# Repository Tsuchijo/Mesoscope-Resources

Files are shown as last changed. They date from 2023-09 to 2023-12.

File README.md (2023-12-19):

# TM-Lab-Mesoscope-Resources

## Arduino Code
Installing Arduino IDE:

    Download Arduino IDE:
        Visit the official Arduino website: Arduino Software.
        Choose the appropriate version for your operating system (Windows, macOS, Linux), and download the installer.

    Install Arduino IDE:
        Run the downloaded installer and follow the on-screen instructions.
        On Windows, you might need to install drivers for the Arduino board during the installation process.

    Open Arduino IDE:
        Once installed, open the Arduino IDE.

Installing and Running a Supplied Program:

    Connect Arduino Board:
        Connect your Arduino board to your computer using a USB cable.

    Select Board and Port:
        In the Arduino IDE, go to Tools > Board and select the appropriate Arduino board (e.g., Arduino Uno).
        Also, go to Tools > Port and select the port to which your Arduino board is connected.

    Open a Supplied Program (Sketch):
        Download the sketch from TriggeringstrobingArduinoCode/
        In the Arduino IDE, go to File > open and open the downloaded sketch

    Verify the Sketch:
        Click the checkmark icon (Verify) to check for any errors in the code. Fix any errors if they occur.

    Upload the Sketch:
        Click the right arrow icon (Upload) to compile and upload the sketch to the Arduino board.

## Lens Adapters

All the lens adapters are parametrically created using this onshape file:

https://cad.onshape.com/documents/2f0def30531779d17ee9e510/w/bf5702dd5ef345ce03ccb7df/e/dbd37cfbbbade1fbfb717a2f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

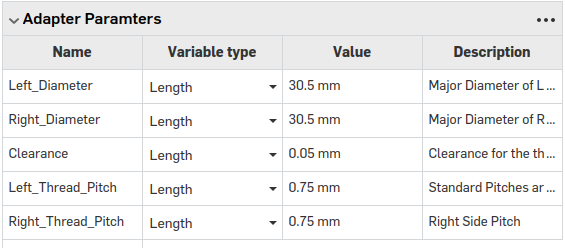
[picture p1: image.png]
Image of the adapter parameters


Adjust these parameters to change the adapters parameters, the diameter is the inner diameter of the lens, pitch is usually 0.5 or 0.75

## Strobing Trigger

### Circuit Diagrams
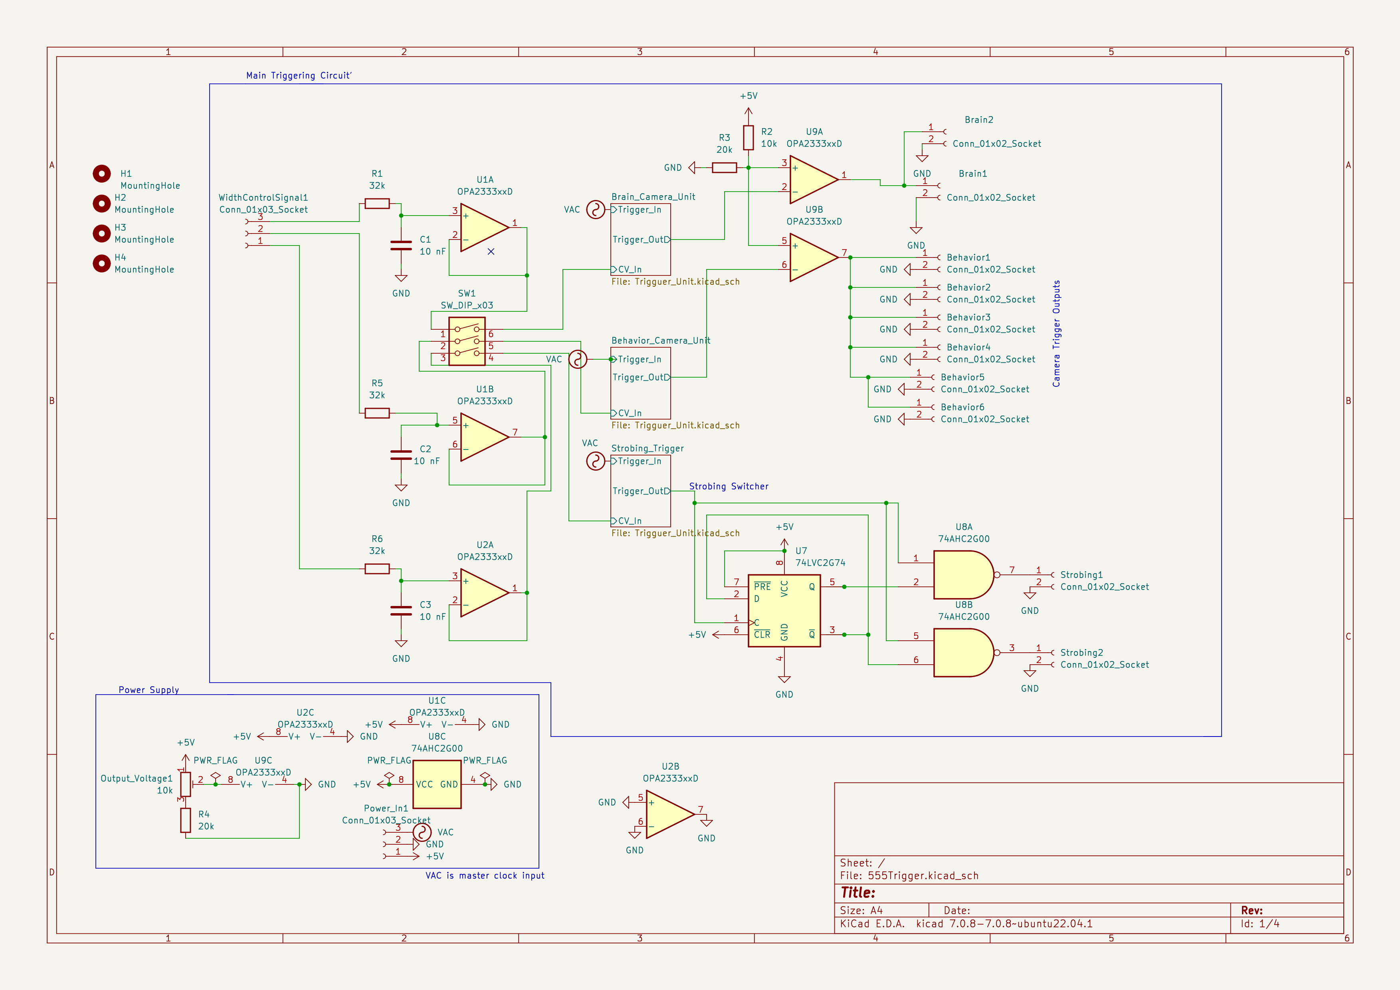
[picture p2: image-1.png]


### Triggering Unit 
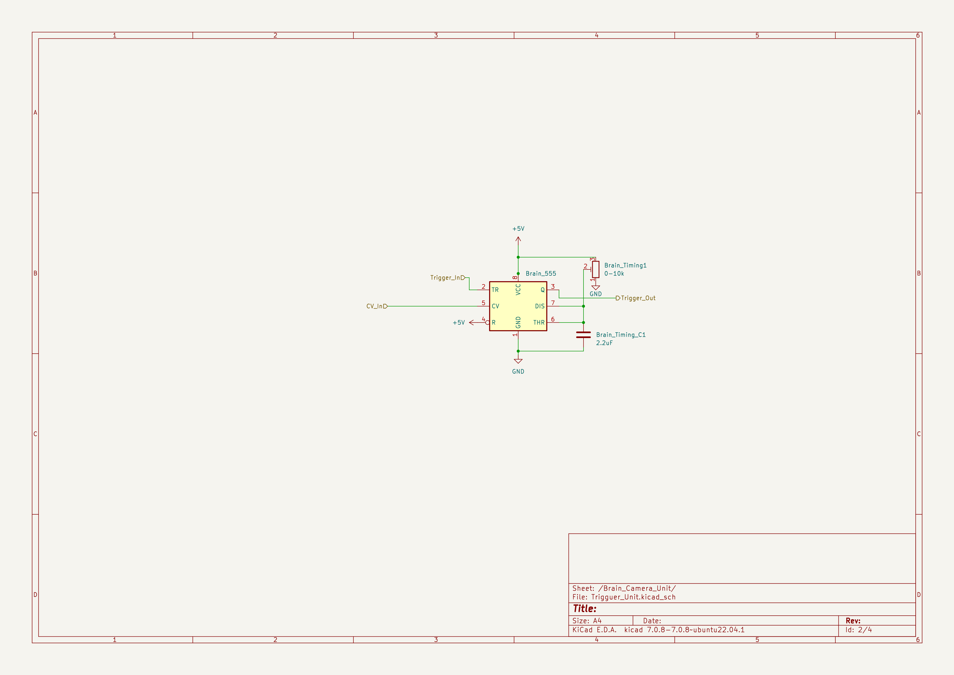
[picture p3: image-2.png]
Sub unit diagram


### Routing 
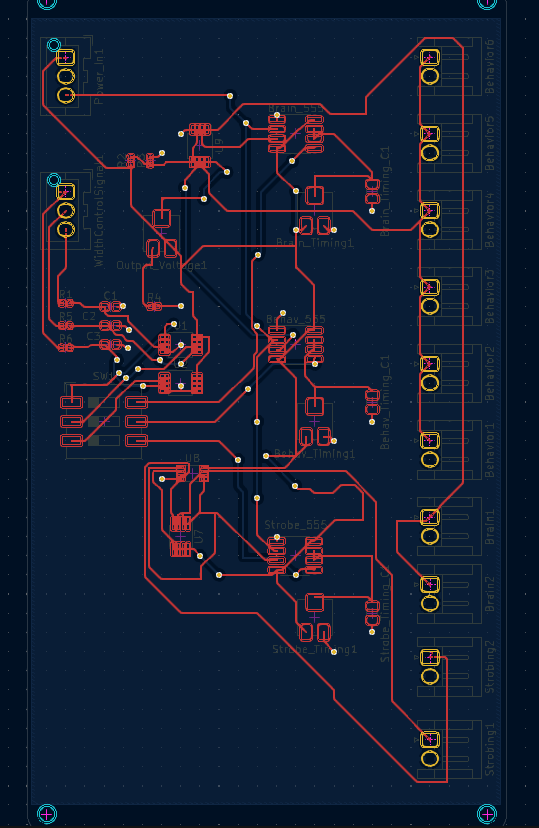
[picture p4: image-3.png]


### I/O
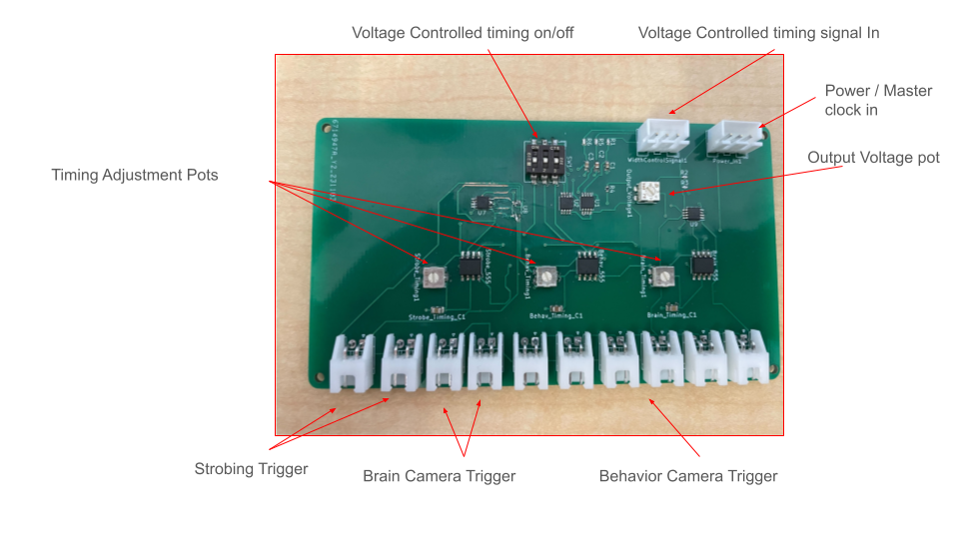
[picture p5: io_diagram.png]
io diagram


For the Master Clock in / power in pin out from left to right is 
- master clock
- ground
- power (5v)

for Timing signal the pinout is
- Brain timing control
- Behavior timing control
- Strobing timing control

with the switches controlling in the same order.

In order to control the width of the timing signal supply a pwm signal to each of the width control signals, with the width corresponding to change in signal. The supplied signal should be greater than 1khz and ideally as high frequency as possible to reduce artifacts

the timing and output pots allow for manual control of timing and output voltage, although each of them can cause errors if pushed to their limits due to variation in their ranges from manufacturing. Never turn the timing pots all the way to the right as that might cause a short

### Using

To use supply a 50hz PWM signal to the master clock with as wide a PWM as possible, the width of the signal corresponding to the maximum possible exposure time.

Supply a 5khz PWM signal for each width control pin in to control the exposure for brain and the behaviour cameras independently. Make sure the switch is switched to ON for the control pin being used. The Width of the PWM signal corresponds with the timing, with the widest signal being the longest exposure time.

Simulation of the circuit can be found at: https://tinyurl.com/ykhpxhtl

### Control Example Code
```import RPi.GPIO as GPIO
import time

# Set GPIO mode and warning
GPIO.setmode(GPIO.BCM)
GPIO.setwarnings(False)

# Define the pin numbers
master_clock_pin = 17
width_control_pin = 18

# Set the frequency for the master clock (50Hz)
master_clock_frequency = 50

# Set the duty cycle for the master clock (99% width)
master_clock_duty_cycle = 99

# Set the frequency for the width control (5kHz)
width_control_frequency = 5000

# Initialize the GPIO pins
GPIO.setup(master_clock_pin, GPIO.OUT)
GPIO.setup(width_control_pin, GPIO.OUT)

# Initialize PWM for master clock
master_clock_pwm = GPIO.PWM(master_clock_pin, master_clock_frequency)
master_clock_pwm.start(master_clock_duty_cycle)

# Function to control the width of the second PWM
def set_width(shutter_speed):
    width_percentage = shutter_speed * 100
    width_control_pwm.ChangeDutyCycle(width_percentage)

# Initialize PWM for width control
width_control_pwm = GPIO.PWM(width_control_pin, width_control_frequency)
width_control_pwm.start(0)  # Start with 0% duty cycle

try:
    # Example: Set shutter speed to 0.5 (50% duty cycle)
    shutter_speed = 0.5
    set_width(shutter_speed)

    # Keep the program running
    while True:
        time.sleep(1)

except KeyboardInterrupt:
    # Clean up on program exit
    master_clock_pwm.stop()
    width_control_pwm.stop()
    GPIO.cleanup()
```

# Throughole Based Triggering System
For making the throughhole 555 trigger there is a .xlsx file with the digikey order needed to create one system. The list can also be found at this link: https://www.digikey.ca/en/mylists/list/3F61W3LRA3. Then the components can be placed on the board based on the silkscreen.

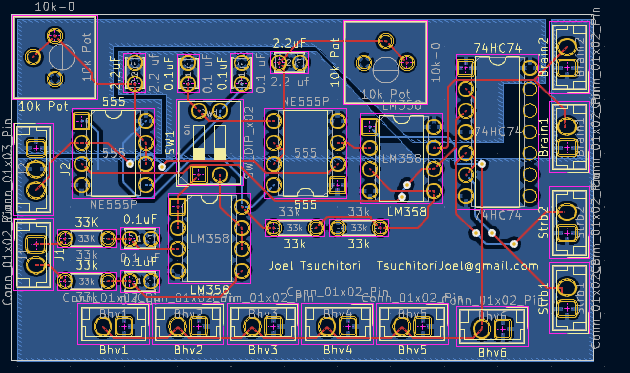
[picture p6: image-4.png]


## Circuit Drawing

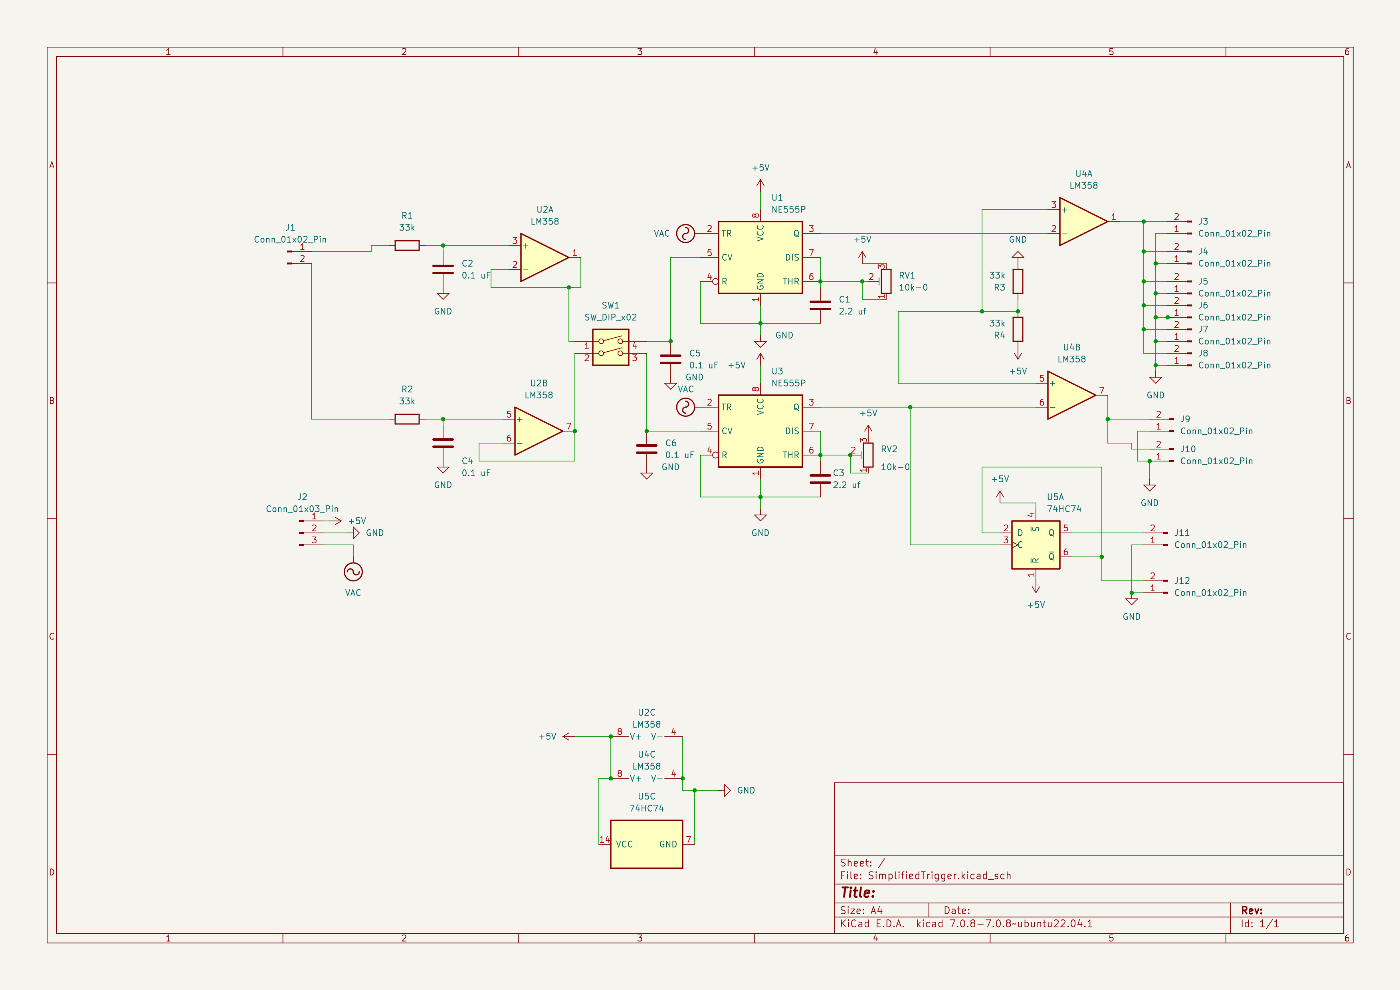
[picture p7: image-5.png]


# Solenoid Driver

The Driver is based on using M7 Mosfet drivers, which max out at ~300 mA of current draw at 12V, anything higher will damage and burn out the driver over time. Not suitable for high power solenoids.

## Circuit Drawing
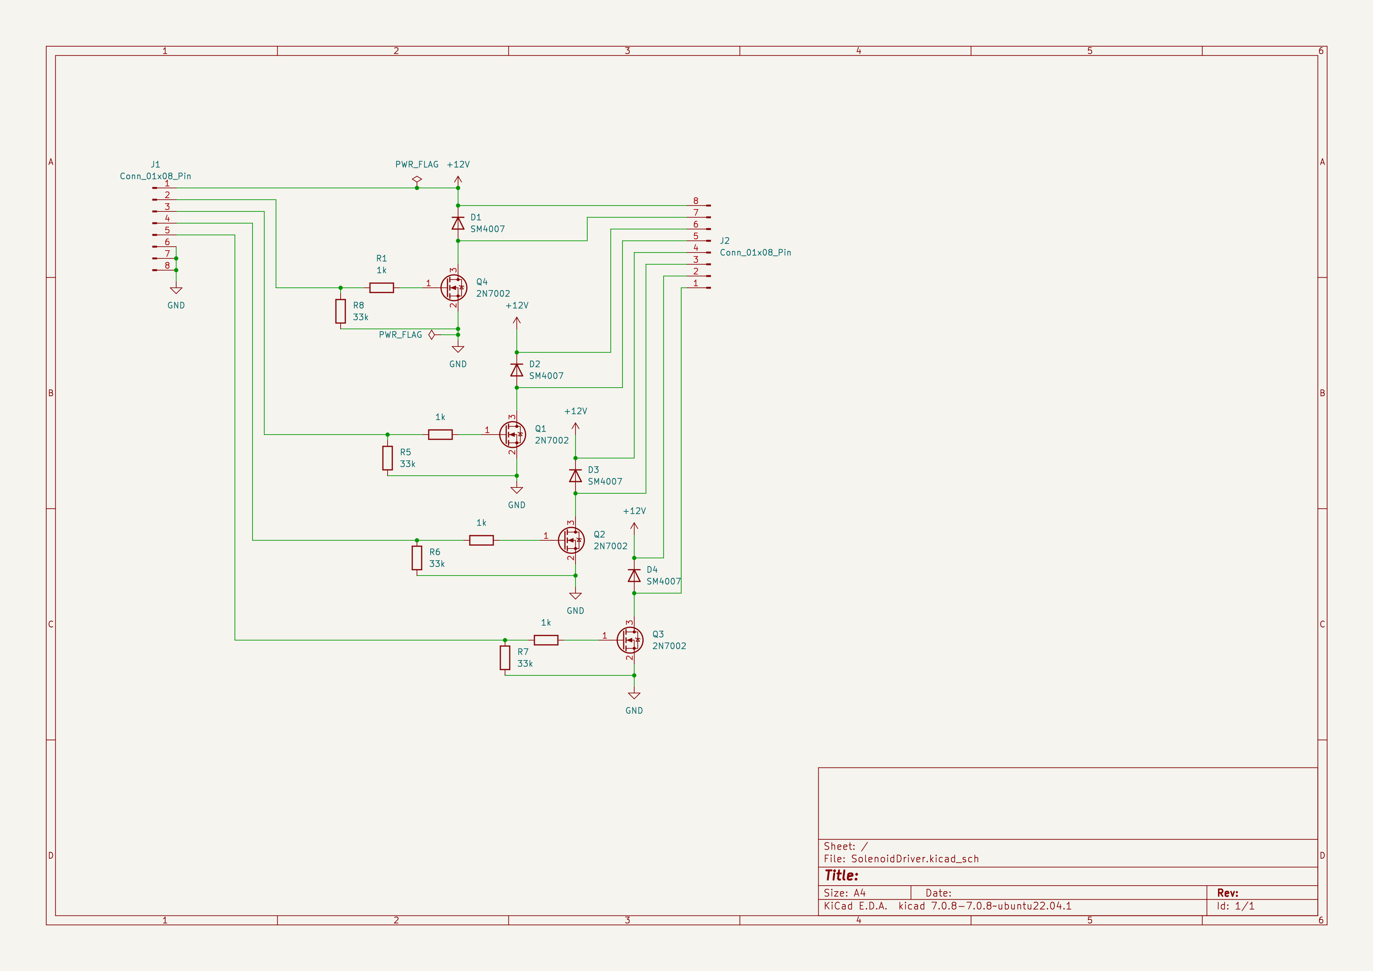
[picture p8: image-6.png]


# Glass Slide Cutting Jigs
https://cad.onshape.com/documents/586ecae177d828403c2f23cb/w/295fcf84d2d2bd0672364755/e/c55ac1745cc839e1a44f1998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

the Glass Slide Cutting Jig is parameterized by a variable table which determines the depth of the first and second cuts, made to cut 8mm diameter glass slides, should be 3d printed on fine print settings.

# Columbia Mouse Cup Clear Sides Model
https://cad.onshape.com/documents/b81ce74945475cb4a4585191/w/58aa1f17095117351b4c242d/e/5ae7ff2c3d7fb6816ba1f3a7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

Clear Sided mouse cup for water reaching task. The sides should be laser cut out of 3mm acrylic, the main cup 3d printed.

# Headfix Mount
https://cad.onshape.com/documents/1d2096fc56ebea0ce0825b22/w/af5d367c825ef3549394acac/e/f6e60455f61b46eaad854045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

Model and Drawing for headfix mount, should be tapped and machined. Used JLCPCB to order the Machined versions.

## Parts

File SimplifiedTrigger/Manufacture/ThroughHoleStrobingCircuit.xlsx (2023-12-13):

Country of Origin may be different at time of shipment.
The HTSUS and ECCN information shown is for informational purposes only and is not a representation or warranty as to the accuracy or reliability of these classifications. All information is provided "as is" and is subject to change without notice. Any use made of the information provided is without recourse to Digi-Key and at the user's risk.
Index | Manufacturer Part Number | Manufacturer Name | Description | Availability | Stock Status | Attrition % | Requested Quantity 1 | Pack Quantity 1 | Pack Type 1 | Digi-Key Part Number 1 | Unit Price 1 | Extended Price 1 | Minimum Order Quantity 1 | Customer Reference | Requested Part Number | Lead Weeks | Datasheet | Reference Designator | US Import Tariff | Note | Part Status | RoHS Status | Moisture Sensitivity Level (MSL) | ECCN | HTSUS | Country of Origin | Environmental Information | Original Part numbers | Image
1 | 3386P-1-103LF | Bourns Inc. | TRIMMER 10K OHM 0.5W PC PIN TOP | 8,644 | In Stock |  | 2 | 2 | Tube | 3386P-103LF-ND | 1.61000 | $3.22 | 1 |  | 3386P-103LF-ND | 11 | https://www.bourns.com/docs/Product-Datasheets/3386.pdf |  | N/A |  | Active | ROHS3 Compliant | Not Applicable | EAR99 | 8533.40.8050 | Costa Rica | https://www.bourns.com/docs/rohs-content/bourns-reach-letter.pdf|https://www.bourns.com/docs/rohs-cofc/cofc_trim3.pdf?sfvrsn=c321a2cb_6 | 3386P-103LF-ND | https://mm.digikey.com/Volume0/opasdata/d220001/medias/images/2383/3386P SERIES.jpg
2 | LM358P | Texas Instruments | IC OPAMP GP 2 CIRCUIT 8DIP | 48,612 | In Stock |  | 2 | 2 | Tube | 296-1395-5-ND | 0.41000 | $0.82 | 1 |  | 296-1395-5-ND | 6 | https://www.ti.com/general/docs/suppproductinfo.tsp?distId=10 |  | May apply on shipments to the U.S. |  | Active | ROHS3 Compliant | Not Applicable | EAR99 | 8542.33.0001 | China |  | 296-1395-5-ND | https://mm.digikey.com/Volume0/opasdata/d220001/medias/images/376/8-DIP.jpg
3 | NE555P | Texas Instruments | IC OSC SINGLE TIMER 100KHZ 8-DIP | 46,237 | In Stock |  | 2 | 2 | Tube | 296-NE555P-ND | 0.46000 | $0.92 | 1 |  | 296-NE555P-ND | 6 | https://www.ti.com/general/docs/suppproductinfo.tsp?distId=10 |  | N/A |  | Active | ROHS3 Compliant | Not Applicable | EAR99 | 8542.39.0001 | Mexico |  | 296-NE555P-ND | https://mm.digikey.com/Volume0/opasdata/d220001/medias/images/376/8-DIP.jpg
4 | CD74HC74E | Texas Instruments | IC FF D-TYPE DUAL 1BIT 14DIP | 2,926 | In Stock |  | 1 | 1 | Tube | 296-12819-5-ND | 0.87000 | $0.87 | 1 |  | 296-12819-5-ND | 6 | https://www.ti.com/general/docs/suppproductinfo.tsp?distId=10 |  | N/A |  | Active | ROHS3 Compliant | Not Applicable | EAR99 | 8542.39.0001 | Malaysia |  | 296-12819-5-ND | https://mm.digikey.com/Volume0/opasdata/d220001/medias/images/4846/296_14-DIP.jpg
5 | B2B-XH-A | JST Sales America Inc. | CONN HEADER VERT 2POS 2.5MM | 1,099,826 | In Stock |  | 11 | 11 | Bulk | 455-B2B-XH-A-ND | 0.12200 | $1.34 | 1 |  | 455-B2B-XH-A-ND | 16 | https://www.jst-mfg.com/product/pdf/eng/eXH.pdf |  | N/A |  | Active | ROHS3 Compliant | 1 (Unlimited) | EAR99 | 8536.69.4040 | China |  | 455-B2B-XH-A-ND | https://mm.digikey.com/Volume0/opasdata/d220001/medias/images/867/B2B-XH-A(LF)(SN).jpg
6 | B3B-XH-A | JST Sales America Inc. | CONN HEADER VERT 3POS 2.5MM | 71,311 | In Stock |  | 1 | 1 | Bulk | 455-2248-ND | 0.21000 | $0.21 | 1 |  | 455-2248-ND | 16 | https://www.jst-mfg.com/product/pdf/eng/eXH.pdf |  | N/A |  | Active | RoHS non-compliant | 1 (Unlimited) | EAR99 | 8536.69.4040 | China |  | 455-2248-ND | https://mm.digikey.com/Volume0/opasdata/d220001/medias/images/889/B3B-XH-A(LF)(SN).jpg
7 | CF18JT33K0 | Stackpole Electronics Inc | RES 33K OHM 5% 1/8W AXIAL | 19,634 | In Stock |  | 4 | 4 | Cut Tape (CT) | CF18JT33K0CT-ND | 0.10000 | $0.40 | 1 |  | CF18JT33K0CT-ND | 17 | https://www.seielect.com/catalog/sei-cf_cfm.pdf |  | May apply on shipments to the U.S. |  | Active | ROHS3 Compliant | Not Applicable | EAR99 | 8533.10.0065 | China | https://www.seielect.com/catalog/cert-of-compliance.pdf|https://www.seielect.com/catalog/reach.pdf|https://www.seielect.com/catalog/SEI-RoHS_Compliance_Status.pdf | CF18JT33K0CT-ND | https://mm.digikey.com/Volume0/opasdata/d220001/medias/images/2453/CF Series 33k.jpg
8 | K104K15X7RF5TL2 | Vishay Beyschlag/Draloric/BC Components | CAP CER 0.1UF 50V X7R RADIAL | 288,776 | In Stock |  | 4 | 4 | Cut Tape (CT) | BC1084CT-ND | 0.23000 | $0.92 | 1 |  | BC1084CT-ND | 17 | https://www.vishay.com/docs/45171/kseries.pdf |  | May apply on shipments to the U.S. |  | Active | ROHS3 Compliant | Not Applicable | EAR99 | 8532.24.0060 | China | https://www.vishay.com/docs/99912/mat_cat_policy.pdf | BC1084CT-ND | https://mm.digikey.com/Volume0/opasdata/d220001/medias/images/4847/56_K102K15X7RF5TL2.jpg
9 | FG14X7R1H225KRT06 | TDK Corporation | CAP CER 2.2UF 50V X7R RADIAL | 9,537 | In Stock |  | 2 | 2 | Cut Tape (CT) | 445-173138-1-ND | 0.52000 | $1.04 | 1 |  | 445-173138-1-ND | 24 | https://product.tdk.com/en/system/files |  | May apply on shipments to the U.S. |  | Active | ROHS3 Compliant | Not Applicable | EAR99 | 8532.24.0060 | China | https://product.tdk.com/en/environment/index.html | 445-173138-1-ND | https://mm.digikey.com/Volume0/opasdata/d220001/medias/images/21/MFG_FG14.JPG
10 | 206-2ST | CTS Electrocomponents | SWITCH SLIDE DIP SPST 50MA 24V | 10,540 | In Stock |  | 1 | 1 | Tube | CT2062ST-ND | 0.83000 | $0.83 | 1 |  | CT2062ST-ND | 12 | https://www.ctscorp.com/wp-content/uploads/206.pdf |  | N/A |  | Active | ROHS3 Compliant | Not Applicable | EAR99 | 8536.50.9065 | Taiwan | https://www.ctscorp.com/wp-content/uploads/ROHS3_DIPTactSwitch.pdf | CT2062ST-ND | https://mm.digikey.com/Volume0/opasdata/d220001/medias/images/4113/MFG_206-2ST.jpg

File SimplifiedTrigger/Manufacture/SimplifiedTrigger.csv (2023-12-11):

Id | Designator | Footprint | Quantity | Designation | Supplier and ref
1 | J1,Brain1,Bhv5,Bhv3,Strb2,Bhv6,Bhv4,Strb1,Bhv2,Brain2,Bhv1 | JST_EH_B2B-EH-A_1x02_P2.50mm_Vertical | 11 | Conn_01x02_Pin
2 | 0.1uF,0.1uF,0.1uF,0.1uF | C_Disc_D3.4mm_W2.1mm_P2.50mm | 4 | 0.1 uF
3 | SW1 | SW_DIP_SPSTx02_Slide_9.78x7.26mm_W7.62mm_P2.54mm | 1 | SW_DIP_x02
4 | 33k,33k,33K,33k | R_Axial_DIN0204_L3.6mm_D1.6mm_P5.08mm_Horizontal | 4 | 33k
5 | 555,555 | DIP-8_W7.62mm | 2 | NE555P
6 | LM358,LM358 | DIP-8_W7.62mm | 2 | LM358
7 | 10k Pot,10k Pot | Potentiometer_Bourns_3386P_Vertical | 2 | 10k-0
8 | 2.2uF,2.2uF | C_Disc_D3.4mm_W2.1mm_P2.50mm | 2 | 2.2 uf
9 | J2 | JST_EH_B3B-EH-A_1x03_P2.50mm_Vertical | 1 | Conn_01x03_Pin
10 | 74HC74 | DIP-14_W7.62mm | 1 | 74HC74

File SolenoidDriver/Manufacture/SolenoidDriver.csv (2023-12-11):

Id | Designator | Footprint | Quantity | Designation | Supplier and ref
1 | R8,R7,R6,R5 | R_0603_1608Metric | 4 | 33k
2 | R4,R3,R2,R1 | R_0603_1608Metric | 4 | 1k
3 | Q4,Q3,Q2,Q1 | SOT-23 | 4 | 2N7002
4 | J2,J1 | PinHeader_1x08_P2.54mm_Vertical | 2 | Conn_01x08_Pin
5 | D4,D3,D2,D1 | D_MELF | 4 | SM4007

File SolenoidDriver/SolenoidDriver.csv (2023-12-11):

# | Reference | Qty | Value | Footprint | DNP
1 | D1, D2, D3, D4 | 4 | SM4007 | Diode_SMD:D_MELF
2 | J1, J2 | 2 | Conn_01x08_Pin | Connector_PinHeader_2.54mm:PinHeader_1x08_P2.54mm_Vertical
3 | Q1, Q2, Q3, Q4 | 4 | 2N7002 | Package_TO_SOT_SMD:SOT-23
4 | R1, R2, R3, R4 | 4 | 1k | Resistor_SMD:R_0603_1608Metric
5 | R5, R6, R7, R8 | 4 | 33k | Resistor_SMD:R_0603_1608Metric

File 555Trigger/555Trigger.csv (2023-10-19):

# | Reference | Qty | Value | Footprint | DNP
1 | Behav_555, Brain_555, Strobe_555 | 3 | TLC555xD | Package_SO:SOIC-8_3.9x4.9mm_P1.27mm
2 | Behav_Timing1, Brain_Timing1, Strobe_Timing1 | 3 | 0-10k | Potentiometer_SMD:Potentiometer_Bourns_3314J_Vertical
3 | Behav_Timing_C1, Brain_Timing_C1, Strobe_Timing_C1 | 3 | 2.2uF | Capacitor_SMD:C_0805_2012Metric
4 | Behavior1, Behavior2, Behavior3, Behavior4, Behavior5, Behavior6, Brain1, Brain2, Strobing1, Strobing2 | 10 | Conn_01x02_Socket | Connector_JST:JST_EH_S2B-EH_1x02_P2.50mm_Horizontal
5 | C1, C2, C3 | 3 | 10 nF | Capacitor_SMD:C_0603_1608Metric
6 | H1, H2, H3, H4 | 4 | MountingHole | MountingHole:MountingHole_2.2mm_M2
7 | Output_Voltage1 | 1 | 10k | Potentiometer_SMD:Potentiometer_Bourns_3314J_Vertical
8 | Power_In1, WidthControlSignal1 | 2 | Conn_01x03_Socket | Connector_JST:JST_XA_B03B-XASK-1-A_1x03_P2.50mm_Vertical
9 | R1, R5, R6 | 3 | 32k | Resistor_SMD:R_0402_1005Metric
10 | R2 | 1 | 10k | Resistor_SMD:R_0402_1005Metric
11 | R3, R4 | 2 | 20k | Resistor_SMD:R_0402_1005Metric
12 | SW1 | 1 | SW_DIP_x03 | Button_Switch_SMD:SW_DIP_SPSTx03_Slide_9.78x9.8mm_W8.61mm_P2.54mm
13 | U1, U2, U9 | 3 | OPA2333xxD | Package_SO:TSSOP-8_3x3mm_P0.65mm
14 | U7 | 1 | 74LVC2G74 | Package_SO:SSOP-8_2.95x2.8mm_P0.65mm
15 | U8 | 1 | 74AHC2G00 | Package_SO:VSSOP-8_2.3x2mm_P0.5mm

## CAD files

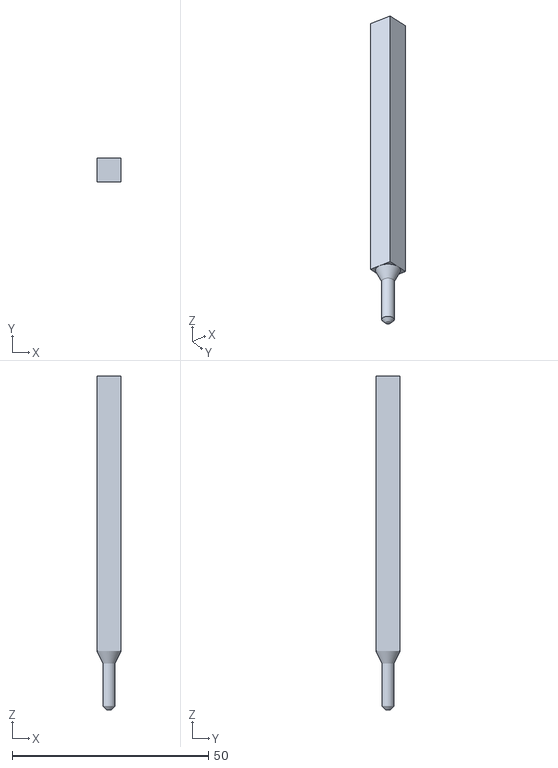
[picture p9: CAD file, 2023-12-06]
Models/EarfixMount.stl
6.21 x 6.21 x 85.0

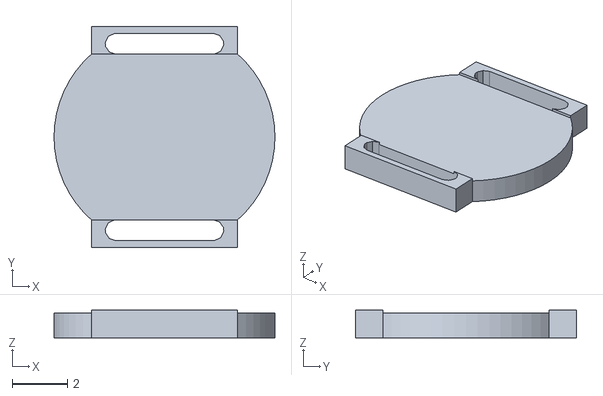
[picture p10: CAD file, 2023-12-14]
Models/GlassCutterJig/Jig2Bottom.stl
8.00 x 8.00 x 1.00

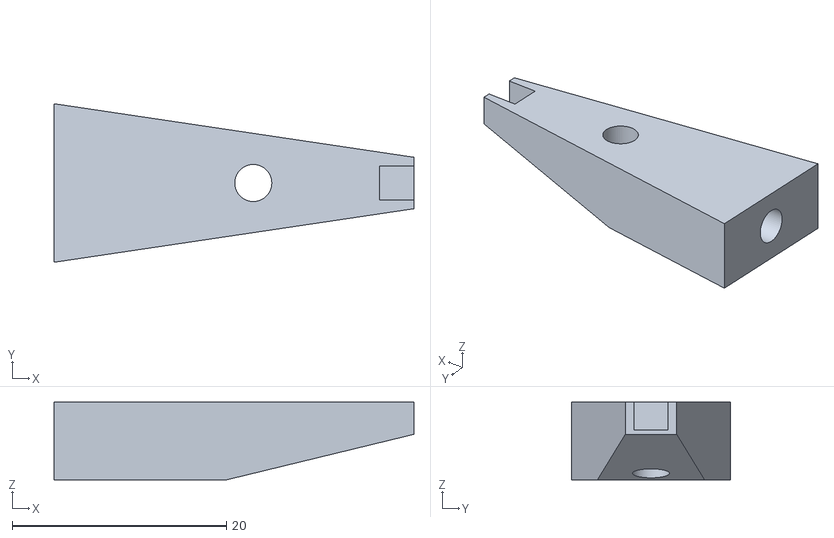
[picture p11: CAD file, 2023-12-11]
Models/Headfix Clamp/HeadClampBottom(1).stl
33.6 x 14.8 x 7.25

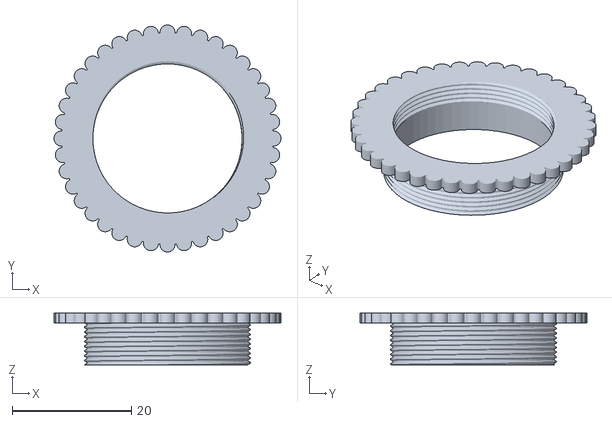
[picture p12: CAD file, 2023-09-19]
Models/LensAdapters/PiCam-Cmount adapter .stl
38.1 x 38.1 x 8.68

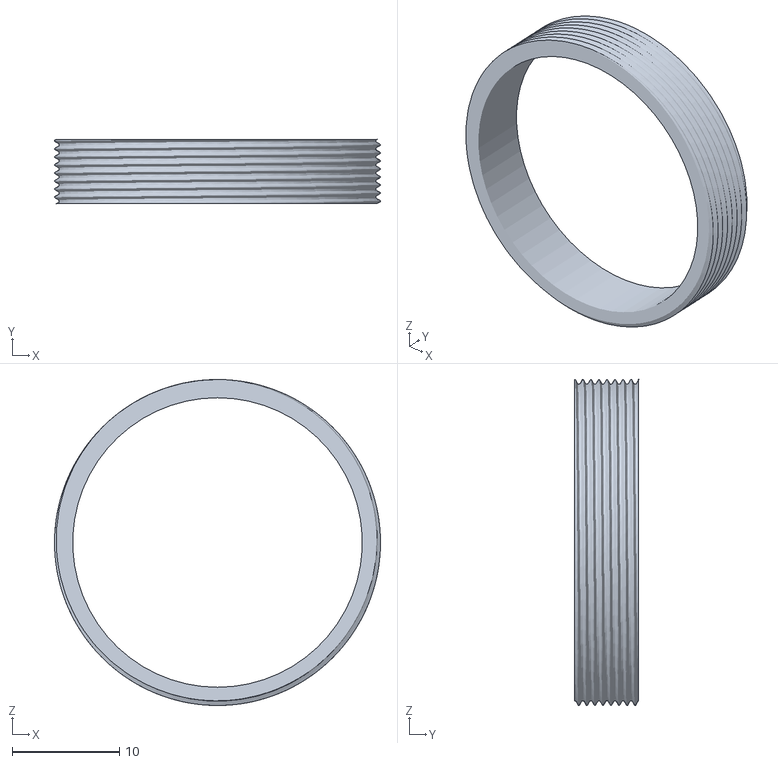
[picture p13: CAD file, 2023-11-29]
Models/LensAdapters/TandemLens/25mm-25mmTandemLensAdapter.stl
30.4 x 6.00 x 30.4

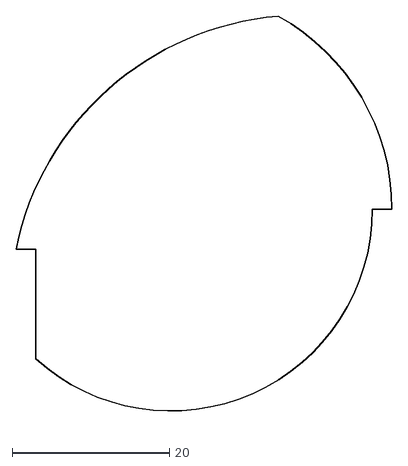
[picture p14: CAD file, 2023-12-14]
Models/MouseCupClear/LaserCutSide.dxf
47.9 x 52.2

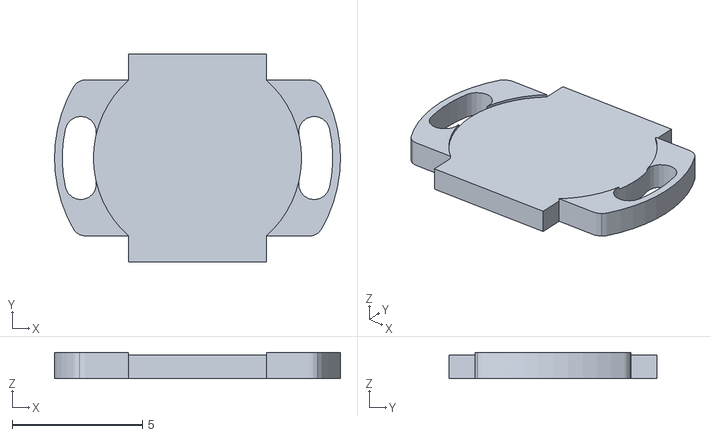
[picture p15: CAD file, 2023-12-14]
Models/GlassCutterJig/Jig1Bottom.stl
11.0 x 8.00 x 1.00

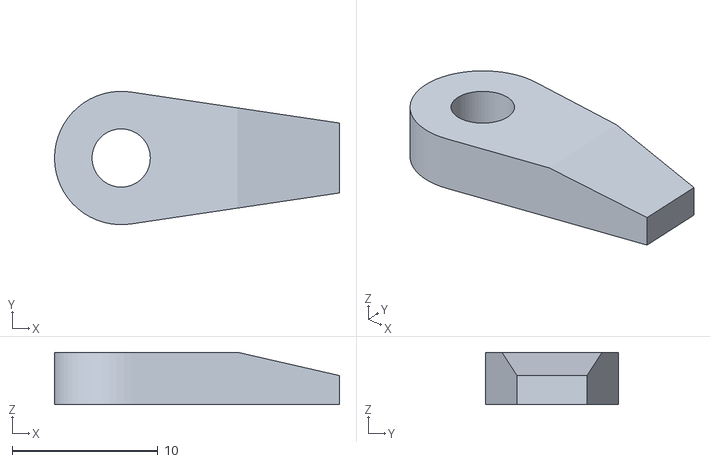
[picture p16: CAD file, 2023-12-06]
Models/Headfix Clamp/HeadClampTop.stl
19.6 x 9.16 x 3.60

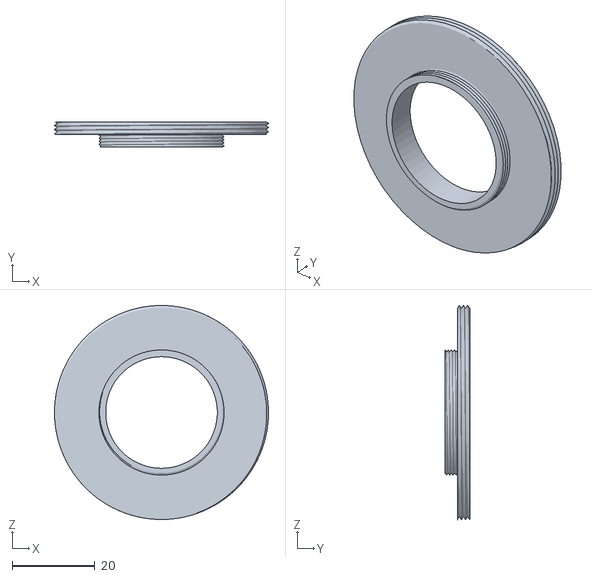
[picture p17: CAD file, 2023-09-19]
Models/LensAdapters/TandemLens/TandemAdapter 30.5-52mm.stl
51.7 x 6.00 x 51.8

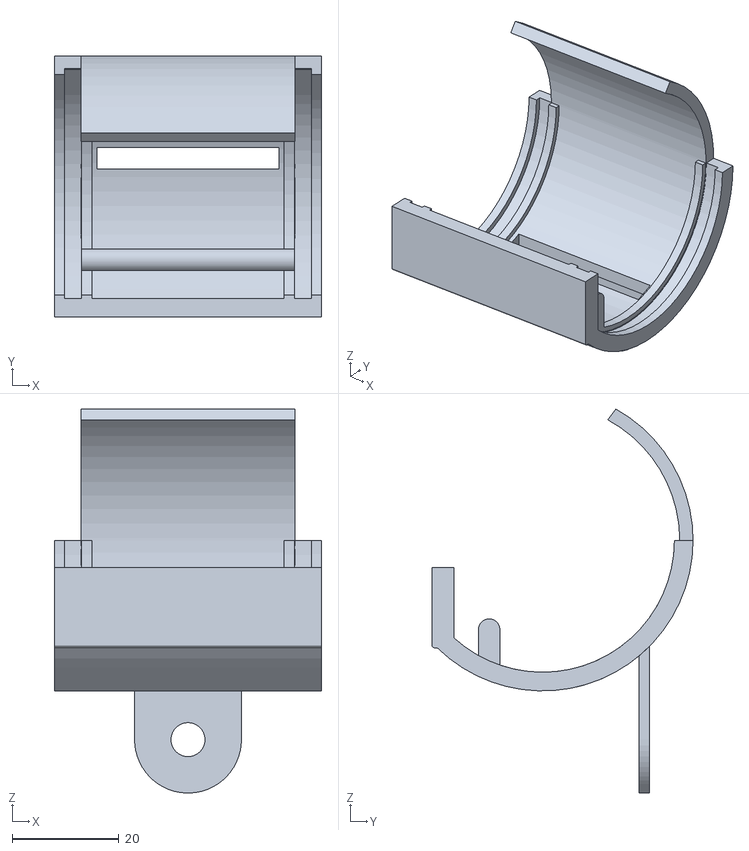
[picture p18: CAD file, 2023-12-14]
Models/MouseCupClear/MouseCupclear.stl
50.0 x 48.9 x 71.8

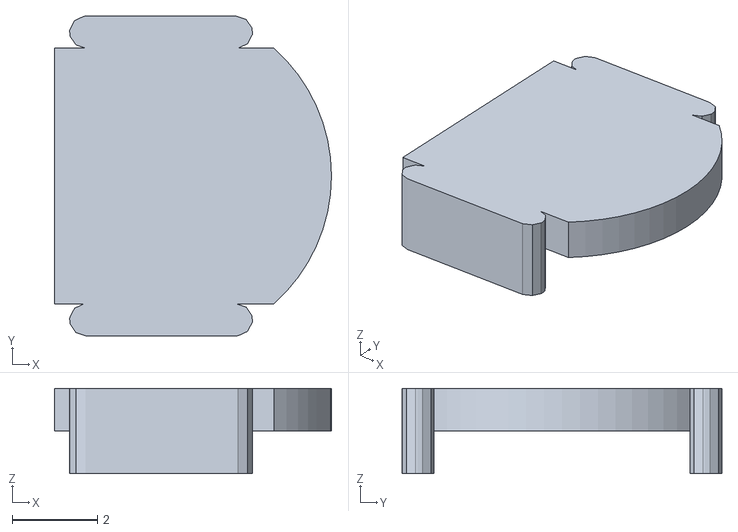
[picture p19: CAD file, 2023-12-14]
Models/GlassCutterJig/Jig2Top.stl
6.50 x 7.50 x 2.00

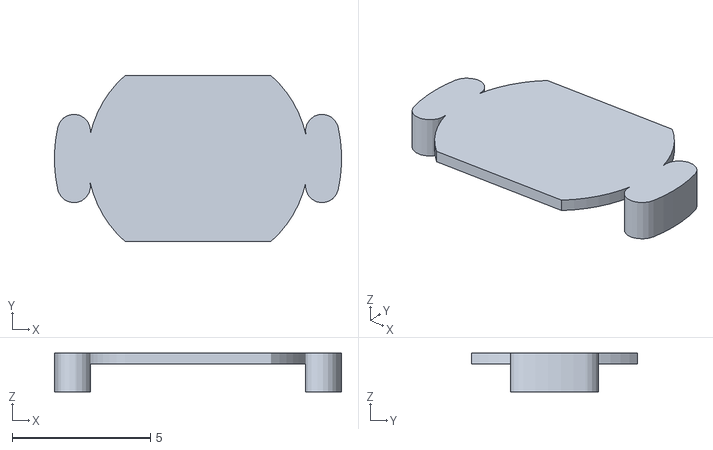
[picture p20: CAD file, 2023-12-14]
Models/GlassCutterJig/Jig1Top.stl
10.4 x 6.00 x 1.40

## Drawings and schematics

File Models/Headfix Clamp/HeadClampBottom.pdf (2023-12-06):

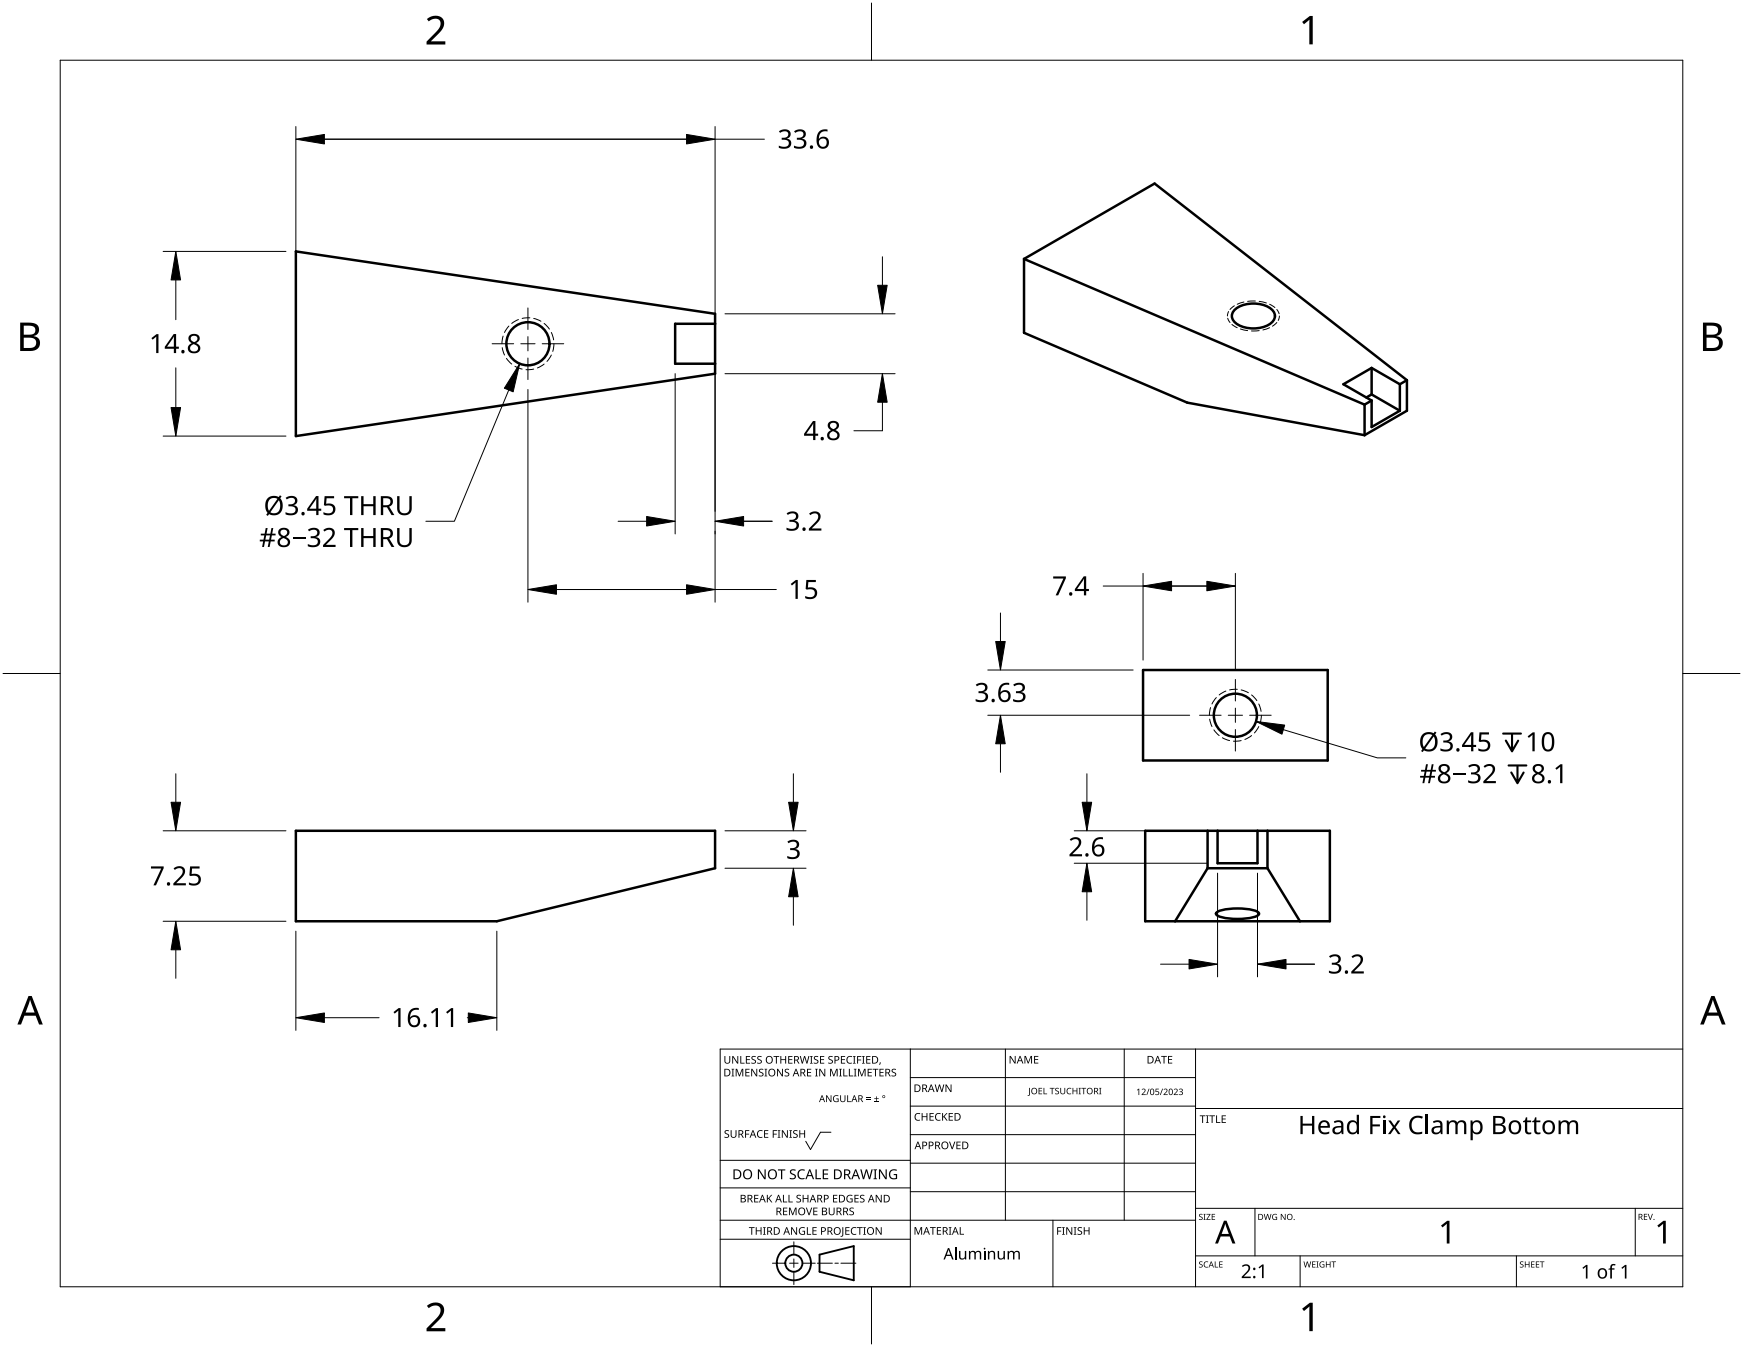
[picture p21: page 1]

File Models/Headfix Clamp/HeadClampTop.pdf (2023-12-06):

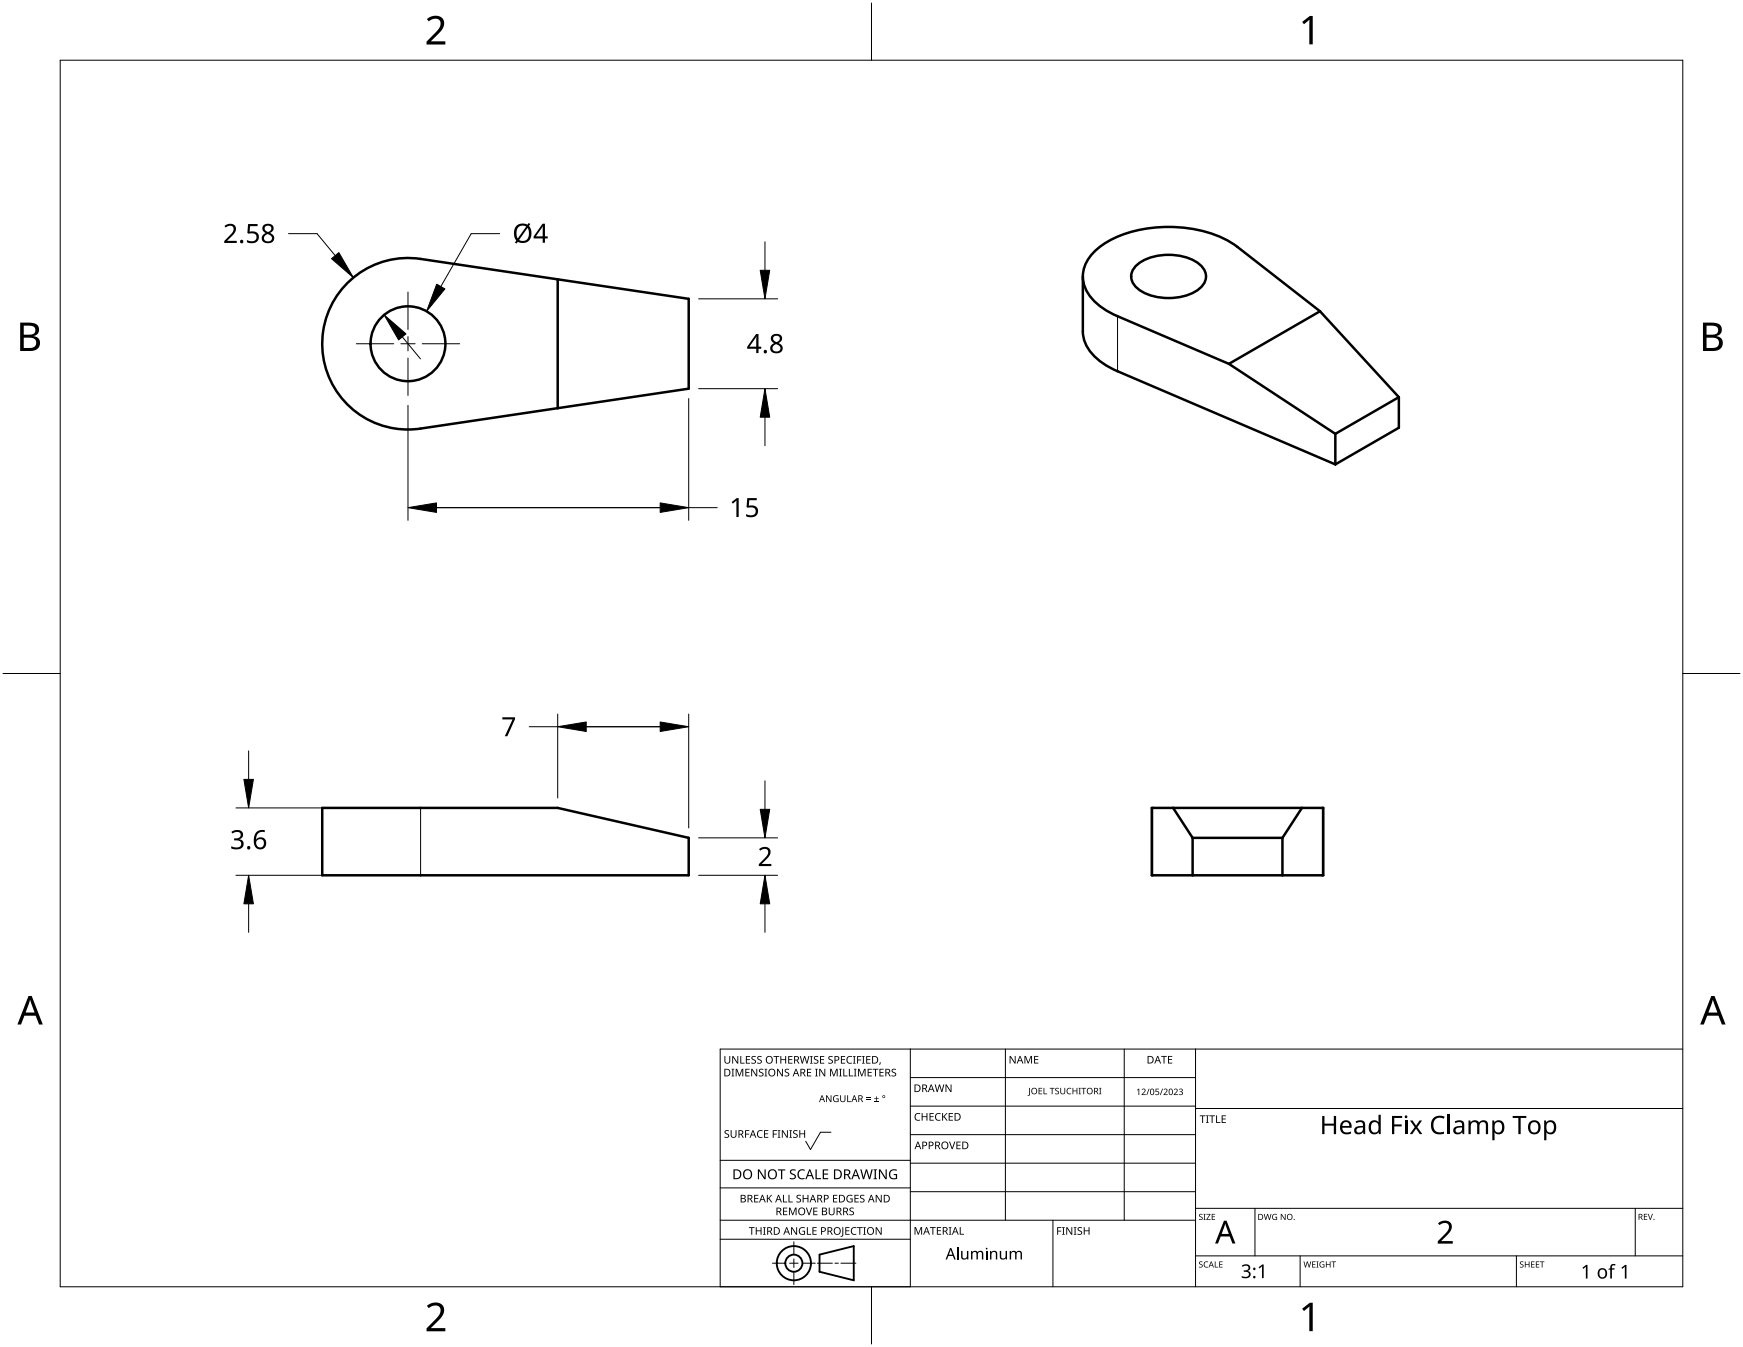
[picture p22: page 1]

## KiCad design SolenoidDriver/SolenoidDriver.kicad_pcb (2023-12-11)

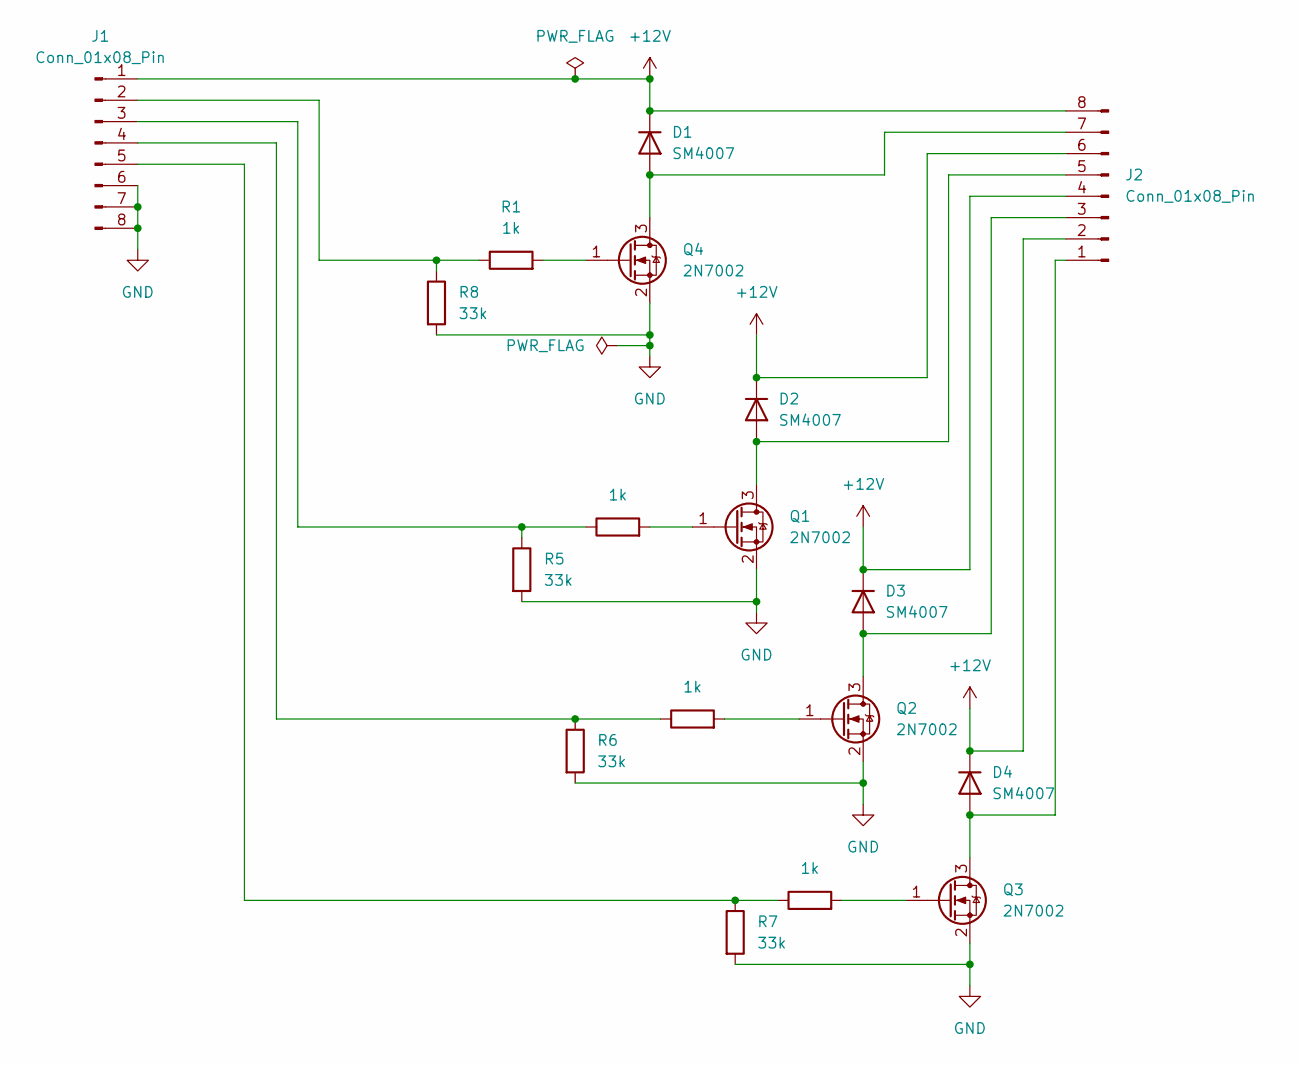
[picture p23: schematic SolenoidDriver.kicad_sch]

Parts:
D1, D2, D3, D4: SM4007; D_MELF
J1, J2: Conn_01x08_Pin; PinHeader_1x08_P2.54mm_Vertical
Q1, Q2, Q3, Q4: 2N7002; SOT-23
R1, R2, R3, R4: 1k; R_0603_1608Metric
R5, R6, R7, R8: 33k; R_0603_1608Metric

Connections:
+12V: D1.1 (K), D2.1 (K), D3.1 (K), D4.1 (K), J1.1, J2.2, J2.4, J2.6, J2.8
GND: J1.6, J1.7, J1.8, Q1.2 (S), Q2.2 (S), Q3.2 (S), Q4.2 (S), R5.2, R6.2, R7.2, R8.2
unnamed: D1.2 (A), J2.7, Q4.3 (D)
unnamed: D2.2 (A), J2.5, Q1.3 (D)
unnamed: D3.2 (A), J2.3, Q2.3 (D)
unnamed: D4.2 (A), J2.1, Q3.3 (D)
unnamed: J1.2, R1.1, R8.1
unnamed: J1.3, R2.1, R5.1
unnamed: J1.4, R3.1, R6.1
unnamed: J1.5, R4.1, R7.1
unnamed: Q1.1 (G), R2.2
unnamed: Q2.1 (G), R3.2
unnamed: Q3.1 (G), R4.2
unnamed: Q4.1 (G), R1.2

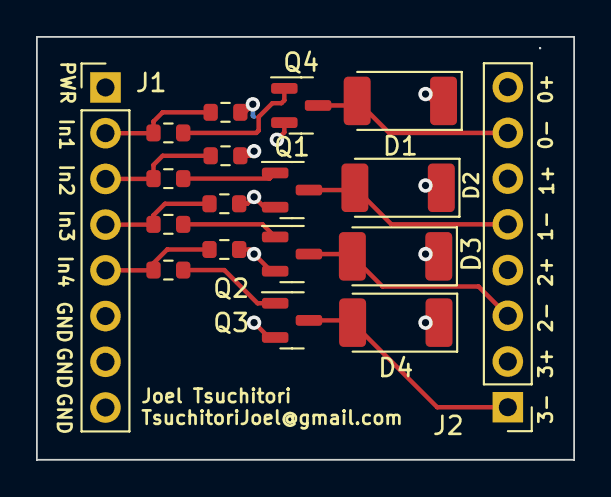
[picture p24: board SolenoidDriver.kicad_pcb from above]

Board: 2 copper layers, 29.8 x 23.5 mm, 18 parts (0 on the bottom side), 14 nets.

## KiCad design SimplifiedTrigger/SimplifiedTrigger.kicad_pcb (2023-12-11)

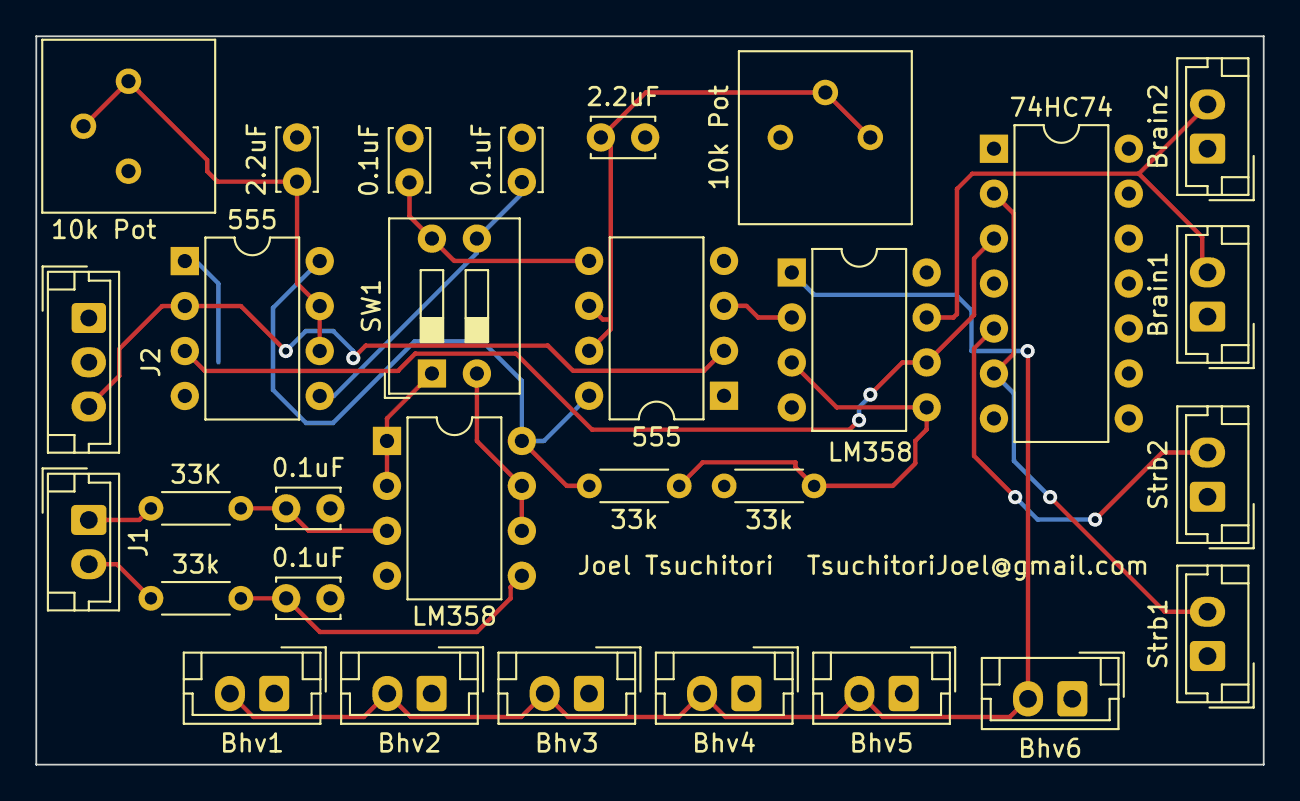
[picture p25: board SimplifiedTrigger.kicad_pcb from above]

Board: 2 copper layers, 69.3 x 41.1 mm, 30 parts (0 on the bottom side), 20 nets.

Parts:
0.1uF, 0.1uF#2, 0.1uF#3, 0.1uF#4: 0.1 uF; C_Disc_D3.4mm_W2.1mm_P2.50mm
2.2uF, 2.2uF#2: 2.2 uf; C_Disc_D3.4mm_W2.1mm_P2.50mm
10k Pot, 10k Pot#2: 10k-0; Potentiometer_Bourns_3386P_Vertical
33K, 33k, 33k#2, 33k#3: 33k; R_Axial_DIN0204_L3.6mm_D1.6mm_P5.08mm_Horizontal
74HC74: 74HC74; DIP-14_W7.62mm
555, 555#2: NE555P; DIP-8_W7.62mm
Bhv1, Bhv2, Bhv3, Bhv4, Bhv5, Bhv6: Conn_01x02_Pin; JST_EH_B2B-EH-A_1x02_P2.50mm_Vertical
Brain1, Brain2: Conn_01x02_Pin; JST_EH_B2B-EH-A_1x02_P2.50mm_Vertical
J1: Conn_01x02_Pin; JST_EH_B2B-EH-A_1x02_P2.50mm_Vertical
J2: Conn_01x03_Pin; JST_EH_B3B-EH-A_1x03_P2.50mm_Vertical
LM358, LM358#2: LM358; DIP-8_W7.62mm
SW1: SW_DIP_x02; SW_DIP_SPSTx02_Slide_9.78x7.26mm_W7.62mm_P2.54mm
Strb1, Strb2: Conn_01x02_Pin; JST_EH_B2B-EH-A_1x02_P2.50mm_Vertical

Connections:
+5V: 10k Pot.3, 10k Pot#2.3, 33k#2.1, 74HC74.1 (~R), 74HC74.4 (~S), 74HC74.14 (VCC), 555.8 (VCC), 555#2.8 (VCC), J2.1, LM358.8 (V+), LM358#2.8 (V+)
GND: 0.1uF.2, 0.1uF#2.2, 0.1uF#3.2, 0.1uF#4.2, 2.2uF.2, 2.2uF#2.2, 33k#3.2, 74HC74.7 (GND), 555.1 (GND), 555.4 (R), 555#2.1 (GND), 555#2.4 (R), Bhv1.1, Bhv2.1, Bhv3.1, Bhv4.1, Bhv5.1, Bhv6.1, Brain1.1, Brain2.1, J2.2, LM358.4 (V-), LM358#2.4 (V-), Strb1.1, Strb2.1
unnamed: 33K.1, J1.1
unnamed: 33k.1, J1.2
unnamed: Bhv1.2, Bhv2.2, Bhv3.2, Bhv4.2, Bhv5.2, Bhv6.2, LM358#2.1
unnamed: Brain1.2, Brain2.2, LM358#2.7
unnamed: 74HC74.5 (Q), Strb2.2
unnamed: 74HC74.2 (D), 74HC74.6 (~Q), Strb1.2
unnamed: 0.1uF.1, 555.5 (CV), SW1.4
unnamed: 2.2uF#2.1, 10k Pot#2.1, 10k Pot#2.2, 555.6 (THR), 555.7 (DIS)
unnamed: 555.3 (Q), LM358#2.2 (-)
unnamed: 0.1uF#2.1, 33K.2, LM358.3 (+)
unnamed: LM358.1, LM358.2 (-), SW1.1
unnamed: 0.1uF#4.1, 33k.2, LM358.5 (+)
unnamed: LM358.6 (-), LM358.7, SW1.2
unnamed: 0.1uF#3.1, 555#2.5 (CV), SW1.3
unnamed: 2.2uF.1, 10k Pot.1, 10k Pot.2, 555#2.6 (THR), 555#2.7 (DIS)
unnamed: 74HC74.3 (C), 555#2.3 (Q), LM358#2.6 (-)
unnamed: 33k#2.2, 33k#3.1, LM358#2.3 (+), LM358#2.5 (+)
VAC: 555.2 (TR), 555#2.2 (TR), J2.3

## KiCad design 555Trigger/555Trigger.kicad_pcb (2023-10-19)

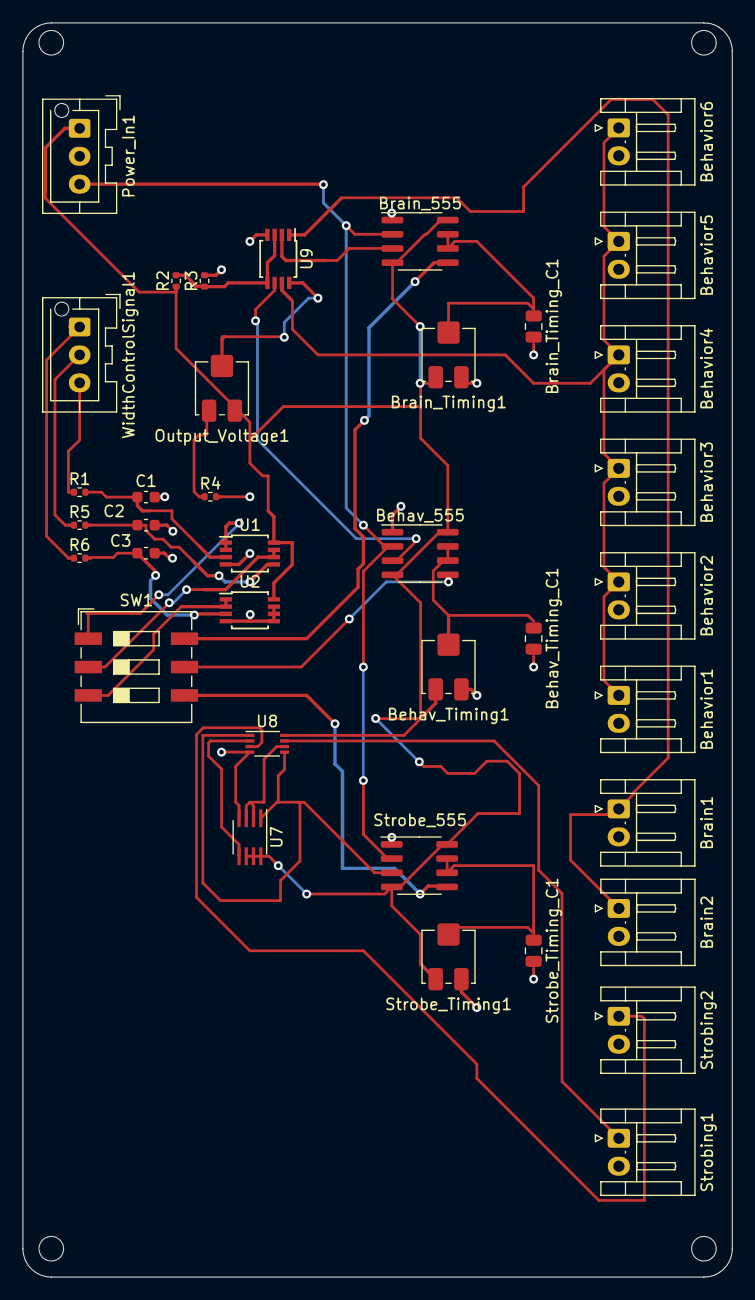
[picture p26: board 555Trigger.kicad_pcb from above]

Board: 2 copper layers, 63.5 x 112.3 mm, 41 parts (0 on the bottom side), 30 nets.

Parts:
Behav_555: TLC555xD; SOIC-8_3.9x4.9mm_P1.27mm
Behav_Timing1: 0-10k; Potentiometer_Bourns_3314J_Vertical
Behav_Timing_C1: 2.2uF; C_0805_2012Metric
Behavior1, Behavior2, Behavior3, Behavior4, Behavior5, Behavior6: Conn_01x02_Socket; JST_EH_S2B-EH_1x02_P2.50mm_Horizontal
Brain1, Brain2: Conn_01x02_Socket; JST_EH_S2B-EH_1x02_P2.50mm_Horizontal
Brain_555: TLC555xD; SOIC-8_3.9x4.9mm_P1.27mm
Brain_Timing1: 0-10k; Potentiometer_Bourns_3314J_Vertical
Brain_Timing_C1: 2.2uF; C_0805_2012Metric
C1, C2, C3: 10 nF; C_0603_1608Metric
H1, H2, H3, H4: MountingHole; MountingHole_2.2mm_M2
Output_Voltage1: 10k; Potentiometer_Bourns_3314J_Vertical
Power_In1: Conn_01x03_Socket; JST_XA_B03B-XASK-1-A_1x03_P2.50mm_Vertical
R1, R5, R6: 32k; R_0402_1005Metric
R2: 10k; R_0402_1005Metric
R3, R4: 20k; R_0402_1005Metric
SW1: SW_DIP_x03; SW_DIP_SPSTx03_Slide_9.78x9.8mm_W8.61mm_P2.54mm
Strobe_555: TLC555xD; SOIC-8_3.9x4.9mm_P1.27mm
Strobe_Timing1: 0-10k; Potentiometer_Bourns_3314J_Vertical
Strobe_Timing_C1: 2.2uF; C_0805_2012Metric
Strobing1, Strobing2: Conn_01x02_Socket; JST_EH_S2B-EH_1x02_P2.50mm_Horizontal
U1, U2, U9: OPA2333xxD; TSSOP-8_3x3mm_P0.65mm
U7: 74LVC2G74; SSOP-8_2.95x2.8mm_P0.65mm
U8: 74AHC2G00; VSSOP-8_2.3x2mm_P0.5mm
WidthControlSignal1: Conn_01x03_Socket; JST_XA_B03B-XASK-1-A_1x03_P2.50mm_Vertical

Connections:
+5V: Behav_555.4 (R), Behav_555.8 (VCC), Behav_Timing1.3, Brain_555.4 (R), Brain_555.8 (VCC), Brain_Timing1.3, Output_Voltage1.1, Power_In1.1, R2.1, Strobe_555.4 (R), Strobe_555.8 (VCC), Strobe_Timing1.3, U1.8 (V+), U2.8 (V+), U7.6 (~CLR), U7.7 (~PRE), U7.8 (VCC), U8.8 (VCC)
/Behavior_Camera_Unit/CV_In: Behav_555.5 (CV), SW1.5
/Behavior_Camera_Unit/Trigger_Out: Behav_555.3 (Q), U9.6 (-)
/Brain_Camera_Unit/CV_In: Brain_555.5 (CV), SW1.6
/Brain_Camera_Unit/Trigger_Out: Brain_555.3 (Q), U9.2 (-)
/Strobing_Trigger/CV_In: SW1.4, Strobe_555.5 (CV)
/Strobing_Trigger/Trigger_Out: Strobe_555.3 (Q), U7.1 (C), U8.1, U8.5
GND: Behav_555.1 (GND), Behav_Timing1.1, Behav_Timing_C1.2, Behavior1.2, Behavior2.2, Behavior3.2, Behavior4.2, Behavior5.2, Behavior6.2, Brain1.2, Brain2.2, Brain_555.1 (GND), Brain_Timing1.1, Brain_Timing_C1.2, C1.2, C2.2, C3.2, Power_In1.2, R3.2, R4.2, Strobe_555.1 (GND), Strobe_Timing1.1, Strobe_Timing_C1.2, Strobing1.2, Strobing2.2, U1.4 (V-), U2.4 (V-), U2.5 (+), U2.6 (-), U2.7, U7.4 (GND), U8.4 (GND), U9.4 (V-)
unnamed: Behav_555.6 (THR), Behav_555.7 (DIS), Behav_Timing1.2, Behav_Timing_C1.1
unnamed: Behavior1.1, Behavior2.1, Behavior3.1, Behavior4.1, Behavior5.1, Behavior6.1, U9.7
unnamed: Brain1.1, Brain2.1, U9.1
unnamed: Brain_555.6 (THR), Brain_555.7 (DIS), Brain_Timing1.2, Brain_Timing_C1.1
unnamed: Output_Voltage1.3, R4.1
unnamed: Strobe_555.6 (THR), Strobe_555.7 (DIS), Strobe_Timing1.2, Strobe_Timing_C1.1
unnamed: Strobing1.1, U8.7
unnamed: Strobing2.1, U8.3
unnamed: C1.1, R1.2, U1.3 (+)
unnamed: SW1.1, U1.1, U1.2 (-)
unnamed: C2.1, R5.2, U1.5 (+)
unnamed: SW1.2, U1.6 (-), U1.7
unnamed: C3.1, R6.2, U2.3 (+)
unnamed: SW1.3, U2.1, U2.2 (-)
unnamed: U7.2 (D), U7.3 (~Q), U8.6
unnamed: U7.5 (Q), U8.2
unnamed: R2.2, R3.1, U9.3 (+), U9.5 (+)
unnamed: Output_Voltage1.2, U9.8 (V+)
unnamed: R6.1, WidthControlSignal1.1
unnamed: R5.1, WidthControlSignal1.2
unnamed: R1.1, WidthControlSignal1.3
VAC: Behav_555.2 (TR), Brain_555.2 (TR), Power_In1.3, Strobe_555.2 (TR)

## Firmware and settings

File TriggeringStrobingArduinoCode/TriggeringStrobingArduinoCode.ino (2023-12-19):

/**
* User Defined Parameters
**/
#define INTERRUPT_RATE_HZ 54
#define PRESCALER_VALUE 64 //Dont change this
#define USE_INTERNAL_TIMER true
const int inputPin = 2; // Assume PWM input is on 

const int outputPins[] = {8, 9, 10}; // PWM output on pin 8, 9, 10
const int strobePins[] = {6, 7}; //PWM ouput pins for 2 strobing outputs (must be 2)

// Each output width is the width of the pulse in millis on each clock cycle, paired by their position in the arraty
// e.g. pins[] = {1,2 } widths[] = {10, 15} gives a 10 millisecond pulse on 1 and a 15 millisecond pulse on 2
const float outputWidths[] = {16, 0.5, 10}; //Width of pulse output in milliseconds (shutter speed)
const float strobeWidth = 9; //Length of Strobing Pulse in Milliseconds


const int numOutput = sizeof outputPins / sizeof outputPins[0];
volatile bool fallingEdgeDetected = false;
volatile bool strobe = false;
long microsCount = 0;

void setup() {
  if (USE_INTERNAL_TIMER){
    initTimer1();
  }
  else {
    // Setup the input as an interrupt pin on ever falling edge
    pinMode(inputPin, INPUT);
    attachInterrupt(digitalPinToInterrupt(inputPin), fallingEdgeInterrupt, FALLING);
  }
  // Specify all output pins
  for (int i = 0; i < numOutput; i++){
    pinMode(outputPins[i], OUTPUT);
  }
  pinMode(strobePins[0], OUTPUT);
  pinMode(strobePins[1], OUTPUT);



  // Enable global interrupts
  sei();
}

void loop() {
  //When the Interrupt is triggered turn on all outputs and reset the timer
  if (fallingEdgeDetected) {
    for (int i = 0; i < numOutput; i++){
      //Set output pins low since camera is triggered on low
      digitalWrite(outputPins[i], LOW);
    }
    //Set Strobing high
    if (strobe) {digitalWrite(strobePins[0], HIGH);}
    else digitalWrite(strobePins[1], HIGH);
    fallingEdgeDetected = false;  // Reset the flag
    microsCount = micros(); // reset the counter
  }

  //For each pin check if clock is over then reset
  for (int i = 0; i < numOutput; i++){
    if (outputWidths[i] * 1000  < micros() - microsCount){
      digitalWrite(outputPins[i], HIGH);
    }
  }
  if (strobeWidth * 1000 < micros() - microsCount){
    if (strobe) {digitalWrite(strobePins[0], LOW);}
    else digitalWrite(strobePins[1], LOW);
  }
}

// Function to initialize Timer1 for 50Hz interrupt
void initTimer1() {
  // Set the Timer1 Control Register A (TCCR1A) to 0
  TCCR1A = 0;

  // Set the Timer1 Control Register B (TCCR1B) to configure the timer
  // Use CTC (Clear Timer on Compare Match) mode
  // Set the prescaler to PRESCALER_VALUE
  TCCR1B |= (1 << WGM12) | (1 << CS11) | (1 << CS10); 

  // Calculate the value to be loaded into the Timer1 register
  // Timer1 operates at 16MHz (Arduino Uno clock frequency)
  // We want a 50Hz interrupt, so the formula is: Timer_value = (Clock_freq / (Prescaler * Target_freq)) - 1
  uint16_t timer1Value = (16000000UL / (PRESCALER_VALUE * INTERRUPT_RATE_HZ)) - 1;

  // Set the Timer1 register (OCR1A) to the calculated value
  OCR1A = timer1Value;

  // Enable the Timer1 Compare A interrupt
  TIMSK1 |= (1 << OCIE1A);
}

void fallingEdgeInterrupt() {
  //detect interrupt
  fallingEdgeDetected = true;
  //Switch which pin is strobing 
  strobe = !strobe;
}

// Interrupt Service Routine (ISR) for Timer1 Compare A
ISR(TIMER1_COMPA_vect) {
  //detect interrupt
  fallingEdgeDetected = true;
  //Switch which pin is strobing 
  strobe = !strobe;
}

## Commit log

2023-09-19 Added Lenses
    [30.5mmTandem.stl, PiCam-Cmount adapter .stl, TandemAdapter 30.5-52mm.stl]
2023-10-06 Added pcb schematics for pulse extender
    [555Trigger.csv, 555Trigger.kicad_pcb, 555Trigger.kicad_sch]
2023-10-11 added filtering and buffers to circuit todo: make one large master control board
    [555Trigger.csv, 555Trigger.kicad_pcb]
2023-10-11 Added subsystems for master board
    [555Trigger.kicad_sch, Trigguer_Unit.kicad_sch]
2023-10-13 changed to SMD
    [555Trigger.kicad_pcb, 555Trigger.kicad_sch, Simulator_test.kicad_pcb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]
2023-10-18 updated timer design
    [555Trigger-B_Cu.gbr, 555Trigger-B_Mask.gbr, 555Trigger-B_Paste.gbr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]
2023-10-19 changed some components to make manufacturing simpler
    [555Trigger-B_Cu.gbr, 555Trigger-B_Mask.gbr, 555Trigger-B_Paste.gbr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]
2023-10-19 changed components to be easier to order
    [555Trigger-B_Cu.gbr, 555Trigger-B_Mask.gbr, 555Trigger-B_Paste.gbr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]
2023-11-29 added more circuit info to readme
    [25mm-25mmTandemLensAdapter.stl, 30.5mmTandem.stl]
2023-11-30 added text description of io
    [555Trigger.kicad_sch]
2023-12-04 added earholder and models folder
    [25mm-25mmTandemLensAdapter.stl, EarHolder.stl, PiCam-Cmount adapter .stl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]
2023-12-06 added Headfix clamp
    [HeadClampBottom.stl, HeadClampTop.stl]
2023-12-06 Modified Earfix
    [EarHolder.stl, EarfixMount.stl]
2023-12-11 Added manufacturing files for solenoid driver and 555 timer
    [HeadClampBottom(1).stl, HeadClampBottom.stl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]
2023-12-13 updated readme with info on ordering components
    [ThroughHoleStrobingCircuit.xlsx]
2023-12-14 Added info and links to other models
    [Jig1Bottom.stl, Jig1Top.stl, Jig2Bottom.stl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]
2023-12-18 Added circuit sim to the readme
2023-12-19 added arduinocode
2023-12-19 added guide for using arduino code
